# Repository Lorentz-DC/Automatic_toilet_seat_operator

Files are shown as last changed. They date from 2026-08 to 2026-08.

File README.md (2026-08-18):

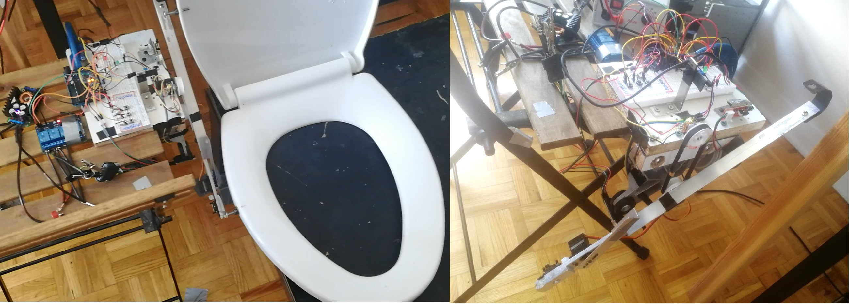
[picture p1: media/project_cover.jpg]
project cover:

# Automatic_toilet_seat_operator
A toggle-activated rotating armature system to raise up and close either the top or both toilet seats. The armature is driven by a car wiper motor and a servo, while the system runs on Arduino code with IR sensors to limit its positions during rotation. 

Load test demostration:

load_test

load testing video with explaination on youtube: https://youtu.be/TG4GU5XdJvA?si=c8EunXvwlVA2-hOE

**Introduction:**

As a guy living with my girlfriend and our cat, I really don't like touching the toilet lids every time I am asked to put the seats down. So I built a automatic toilet seat operator, featuring a set of rotating aluminum armature with a car wiper motor driving the main arm, and a servo motor bolted to the end of the main arm driving a smaller arm. 

The main idea of the design is that when activated, the armature will catch the bolts attached to the toilet lids, and lift up either the top lid or both of the lids, and then push the lids back down. When the main arm alone rotates in clockwise direction, it will only catch the bolt on the upper lid and lift it up; When the servo motor spins down the smaller arm, the main armature will be extended to reach and catch the front bolt of the bottom lid; Therefore, when the arm lifts, both of the lids will be lifted. To lower the seats, the armature simply rotates in reverse to push the lids over, after which they will fall back down themselves. 

With this said, the current version of the code logic works best on a slow closing toilet seat, since otherwise for a set of free closing toilet seat, the lids will slam loudly every time they are pushed back down. 

Hardware View:
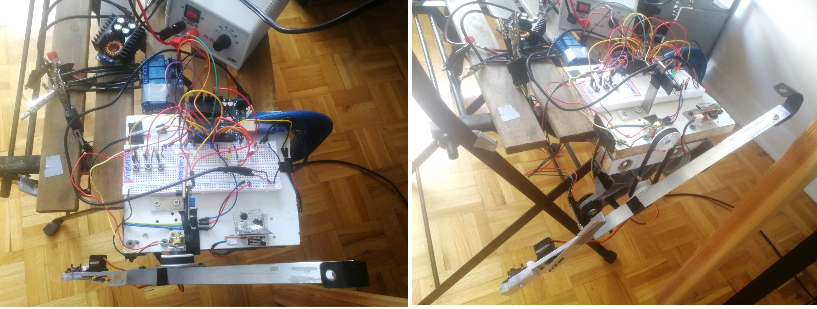
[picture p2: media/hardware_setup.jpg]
Hardware View:

 
**Main Components:**

The main wiper motor is activated by a 2-relay system powered by a 12V 2A DC source with an optional step-down buck converter to regulate speed and torque,  while the Arduino and servo motor can be powered by a standard 5v phone charger. Preferably, the servo motor should have its own power supply so that it does not sag the current on the arduino. 

The mechanism is controlled by 3 toggle buttons: Button 1 raise the top lid. Button 2 latches the small arm down with the servo, extending the main arm, and then the main arm lifts up both lids. Button 3: reverses the main arm to push the lids back down. 

The rotating arm tells its position by two IR sensors: bottom IR sensor for homing position, and a top IR sensor for when the arm reaches to about 90 degree zenith of rotation. On initial start up, the system will detect if the arm is resting at home position to allow inputs, if not, the system will enter a float warming state and a manual reset is required to bring the armature back to homing position. 
There is also a rotation tracking system featuring a set gears with a timing belt coupled to the motor shaft and to a potentiometer, however, this is an optional redundancy system added for extra safety. 

Due to the design, the servo motor casing cannot allow the armature to rotate freely the full 360 degree. For safety, a limit switch is placed in the path of the servo casing, and will stop all system movements if activated. In this case, a float state warning will also activate demanding manual reset. I've had an unfortunate test incident where my faulty code failed to activate the limit switch and the servo casing hit the wood block, as it was at the time running on a 12V 15A DC source, there was so much torque that the plastic servo casing got ripped right off the aluminum arm. 

Wiring Diagram:
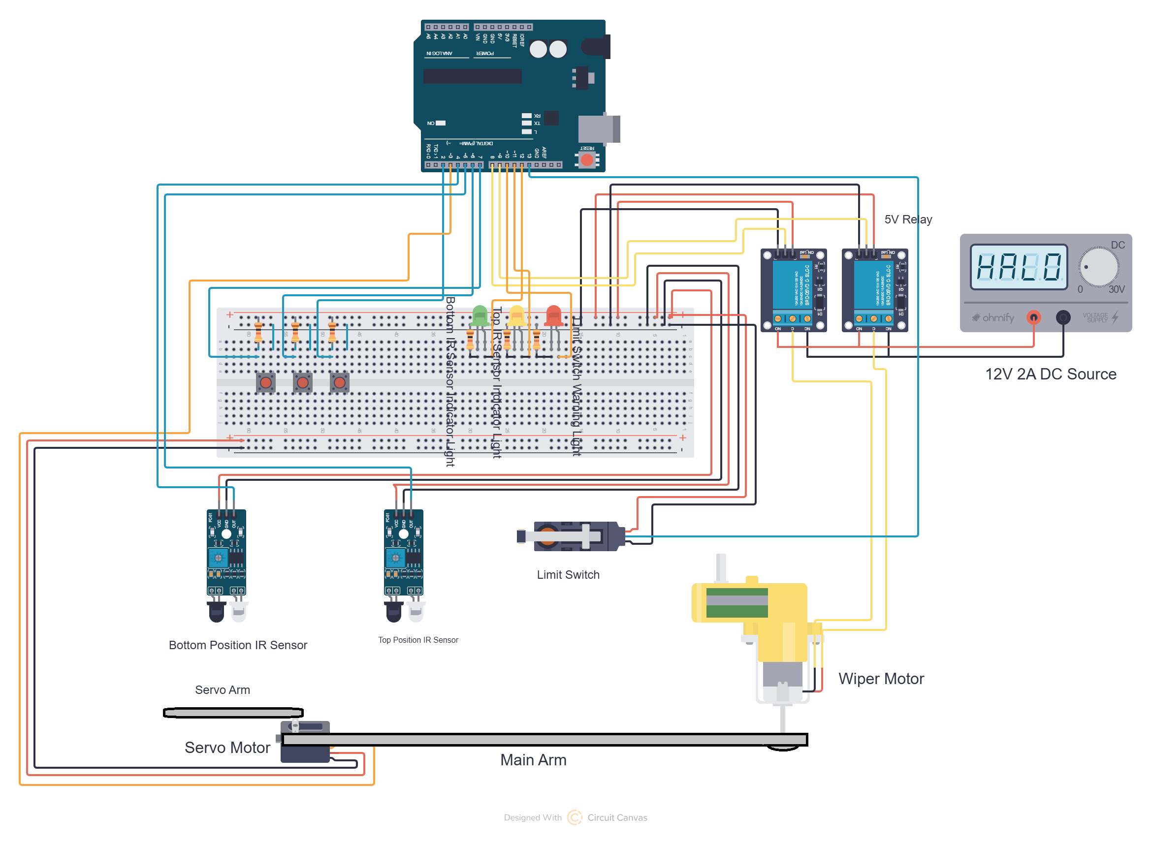
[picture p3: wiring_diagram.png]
Wiring Diagram:


**Relay and Motor Wiring:**

2-relay H-Bridge: I used a 2-relay configuration from a 4-channel module, wiring the motor leads directly to the Common (COM) terminals. This design Electrical Interlock: Normally Closed (NC) pins connect to system Ground, and Normally Open (NO) pins tie to the positive DC motor supply line. This physical wiring layout makes it structurally impossible to create a direct short-circuit across the DC power supply, regardless of code errors. 

Relay wiring diagram:

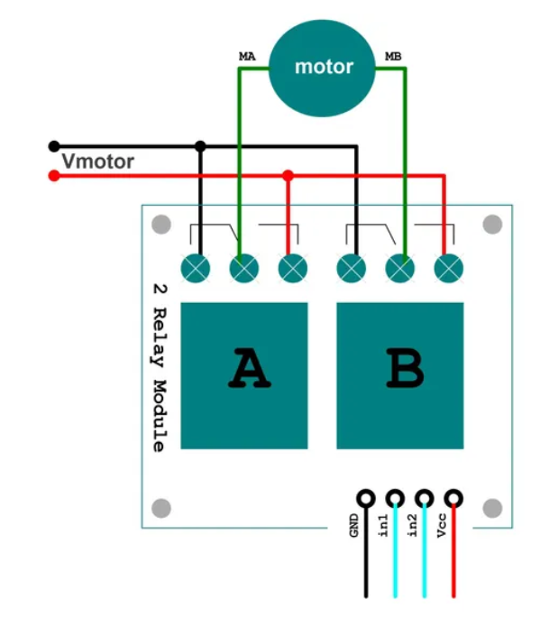
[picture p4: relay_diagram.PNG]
Relay wiring diagram:


**Armature Movement:**

Sequence of movement:
1. lifting up only the top lid;
2. Reverse to push lid down;
3. lifting up both lids by activating the servo and extending the arm;
4. Reverse to push both lids down.

Demonstration of movement logic of the armature:

armature demo

YouTube video link: https://youtu.be/BwDyFDnwye8?si=BkIoQYhQGPaKe0z8

**Arduino Code Structure:**

Arduino code file:
Arduino code file:

The software is organized into three clean layers that split reading sensors, deciding what to do, and moving the motor. This prevents glitches and keeps the hardware safe. 

1. Sensor & Button Inputs (Modular Functions): Functions like IR_Sensors(), Limit_Switch(), and the button controllers run continuously on every loop cycle. They read input data, and translate button presses into simple internal request flags. 

2. Brain & Decision Engine (Switch-Case Structure):The core logic uses a clean switch-case state machine. It handles one step at a time (like HOME, LATCHING, or LIFTING) and  blocks out the other states. Instead of turning on pins directly, this section only updates internal state-flag variables to map out the desired direction. 

3. Motor Driver (Main Loop Activation):Physical relay pins are only permitted to switch at the very end of the main loop(). This dedicated output block acts as a gatekeeper: it checks key state-flag motion variables (e.g: clockwise_direction_state, motion_activate, and servo_liftdown) and executes the final movement on the armature.

Code logic flowchart
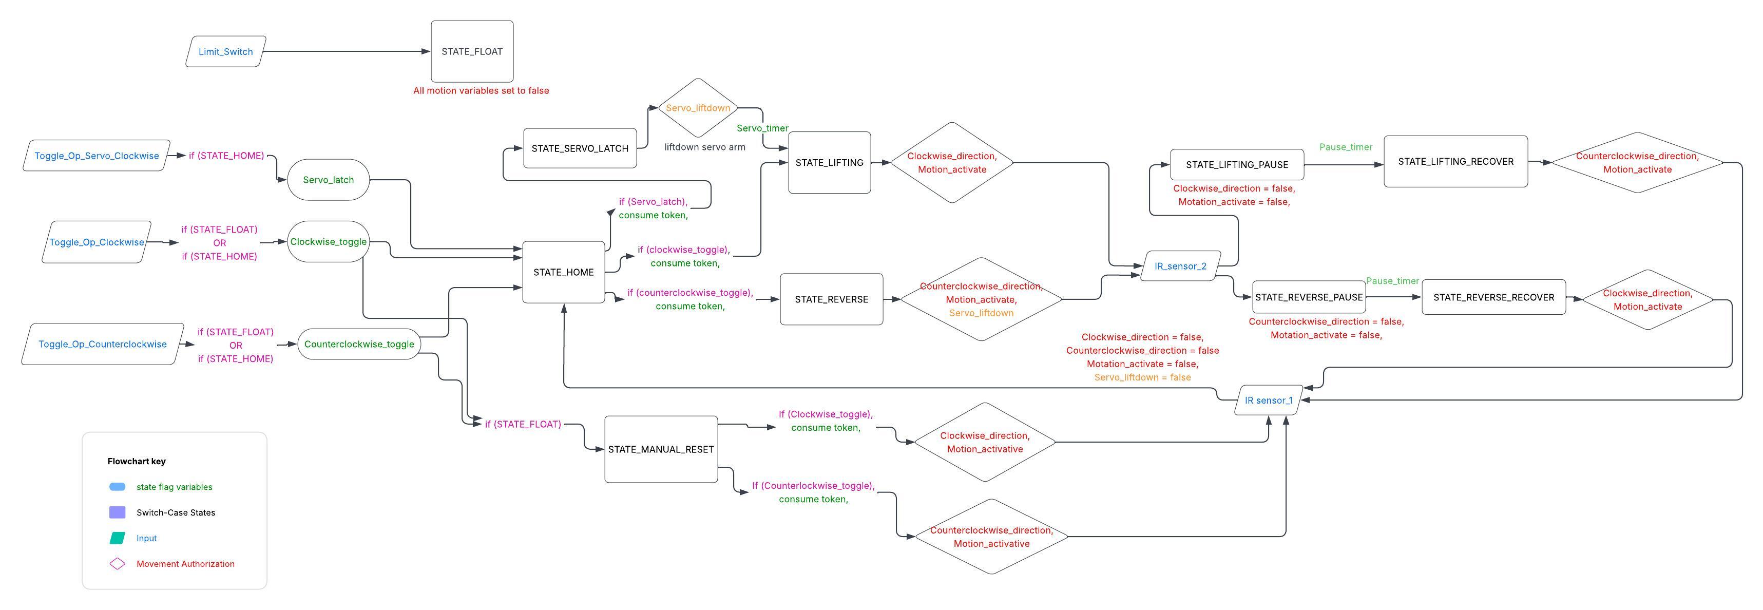
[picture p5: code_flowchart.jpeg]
Code logic flowchart:


**Additional Features:**

**Rotation tracking with potentiometer and 3D-printed GT2 sear set**

While the IR sensors are sufficient to limit arm rotation, I added a redundancy rotation tracking system with a potentiometer and GT2 gear-belt set, where the main arm gear is coupled around the motor shaft, and the potentiometer gear sits on the potentiometer above. When the main arm rotates, the potentiometer will have a 1-1 ratio rotation, and the Arduino will pick up its analog reading (0-1023) and map on to the rotation angle. However this system is not very accurate and prone to gradual slippage, so I've not incorporated it into the main program. Nevertheless, in the arduino code, the tracking function is there, and will print out the real-time rotation data of the potentiometer on the monitor. 

the main reference for my Fusion design is as follows: 
https://youtu.be/PDNIiLSTzG4?si=cXLuie5WhYatIrrd  

3D printed potentiometer GT2 gear set:
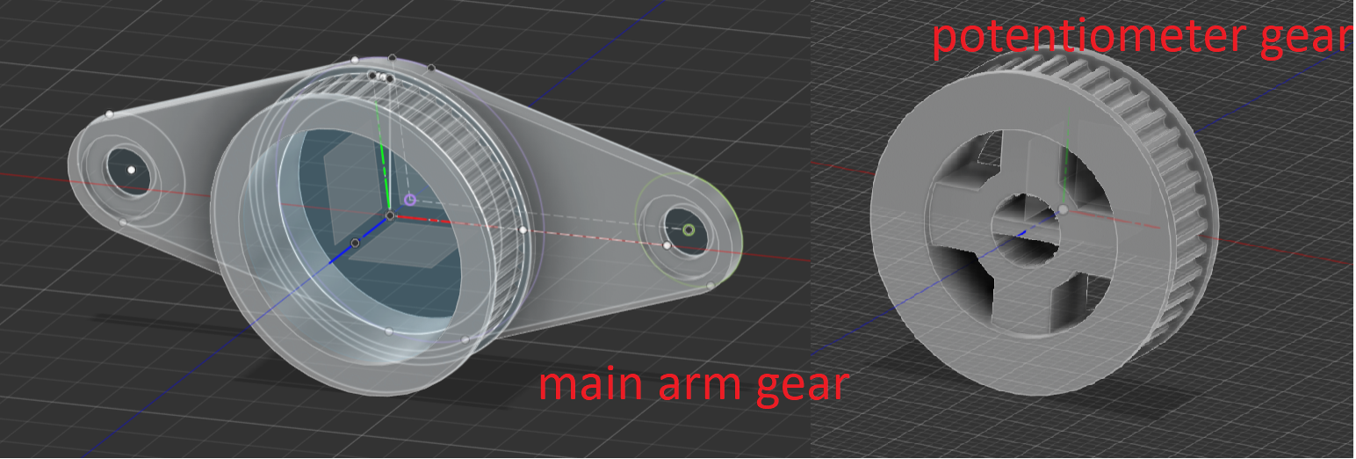
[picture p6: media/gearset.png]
3D printed potentiometer GT2 gear set

the Autodesk Fusion files can be found in the main repository: 

potentiometer gear  
main gear

**Voltage Control and Current Protection:**

Step-down buck converter with CV and CC control (optional): controls main arm movement speed by adjusting step-down voltage; Controls torque by adjusting current ceiling. 

TVS diodes: soldered Transient Voltage suppression diodes across relay terminals for voltage spike protection on the motor side.

Relay protection:
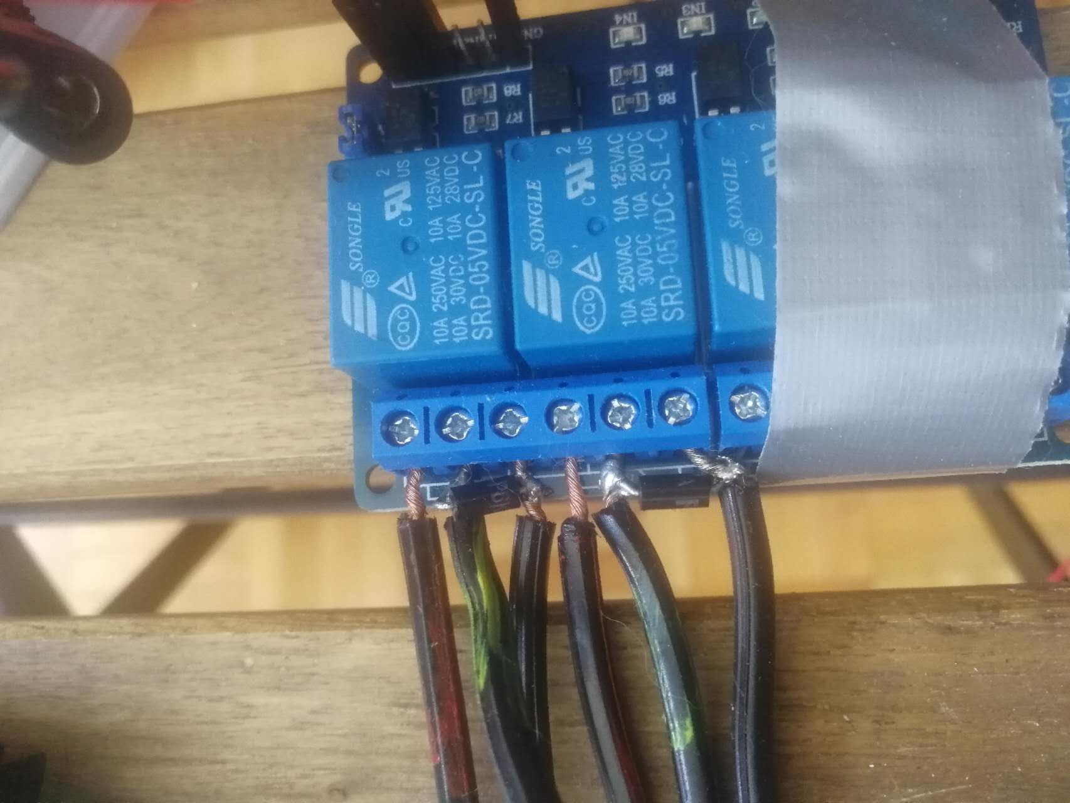
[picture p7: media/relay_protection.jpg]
Relay protection


**Upcoming bathroom Installation:**

As this project has been successfully tested, the next step will be actual installation in the bathroom so that the system will be fully functional. Which will involve many more upcoming works: 

Upgrading push buttons; 

Adding a touchless motion sensor relay switch to power on and off the system upon entering and exiting the bathroom; 

Environment-proofing, wiring and electrical safety; 

Slotted L brackets for position calibration (front-back, up-down, left-right); 

Convincing my gf to actually put it next to the toilet, which would perhaps, be the ultimate challenge.

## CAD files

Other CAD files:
Main_Gear_update_Jul08.f3d
Potentiometer_Gear_Update_Jul08.f3d

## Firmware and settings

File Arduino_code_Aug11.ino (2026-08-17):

#include <Servo.h>
Servo myServo;  // Create a servo object

// Pin Configuration
const int Servo_output_pin = 3;
const int IR_sensor1_pin = 4;  // Reset position (Lid down / Home)
const int IR_sensor2_pin = 5;  // Stop position (Lid fully up / Zenith)
const int Pot_pin = A0; // Potentiometer input
const int limit_switch_pin = 13; // Critical material fail-safe
const int clockwise_output_pin = 8;    // ACTIVE LOW (CW Lift Relay)
const int counterclock_output_pin = 9;  // ACTIVE LOW (CCW Lower Relay)
const int clockwise_servo_toggle_pin = 2;
const int clockwise_toggle_pin = 6;
const int counterclock_toggle_pin = 7;
const int LED1_pin = 12;  // sensor1 green light 
const int LED2_pin = 11;  // sensor2 yellow light
const int LED3_pin = 10;  // Limit Switch warning red light


// Potentiometer range:
/* Analog values range from 0 to 1023: starting point (lowest): 1023; Max rotation (highest): 0; UPLIFT ROTATING: CLOCKWISE
resting lowest: 970; home range: 750-850; zenith range: 400-350

const int POT_REVERSE_ZENITH_TARGET = 930; //arm at zenith pushing lid down
const int POT_HOME_TARGET = 655;    // resting position
const int POT_ZENITH_TARGET = 225;  // fully lift up 
const int POT_BALLPARK_TOLERANCE = 40; // 40-digit deadband tolerance for belt slop
*/

// // --- State management ---
enum SystemState { 
STATE_FLOAT, 
STATE_HOME, 
STATE_Servo_latch,
STATE_LIFTING, 
STATE_PAUSED, 
STATE_LIFTING_RECOVER, 
STATE_REVERSE, 
STATE_REVERSE_PAUSED, 
STATE_REVERSE_RECOVER,
STATE_MANUAL_RESET
};
// NEW: System boots into FLOAT state to handle initial position confirmation safely
SystemState current_state = STATE_FLOAT;  

// NEW: Ballpark tracking condition outputs
/*
boolean pot_at_home = false;
boolean pot_at_zenith = false;
boolean pot_at_reverse_zenith = false;
*/

boolean sensor1_activate = false;
boolean sensor2_activate = false;

boolean Clockwise_direction = false;
boolean Counterclock_direction = false;
boolean Motion_activate = false;

boolean Clockwise_toggle = false;
boolean Counterclock_toggle = false;

//clockwise toggle
boolean old_input_state_clockwise = HIGH;
bool current_button_state_clockwise= HIGH;  

boolean old_input_state_servo = HIGH;
boolean current_input_state_servo = HIGH;

unsigned long servo_start_time = 0;
bool servo_timer_state = false;


//counterclock toggle 
boolean old_input_state_counterclock = HIGH;

boolean Servo_latch = false;
boolean Servo_liftdown = false;
boolean blink_sequence = false;
boolean LED_blink_state = LOW; 

// --- Non-blocking timers --- 
unsigned long previousMillis = 0;
const long blink_interval = 500; // Frequency of Serial updates and reading (250ms)
const long print_interval = 50;
// Non-blocking pause tracking variables
unsigned long pause_start_time = 0;
const unsigned long pause_duration = 3000; // Safe 0.5-second electrical discharge window
// NEW: Boot/Homing timeout guard variable
const unsigned long servo_interval = 500;


bool IR_Sensors() {
  // Read raw inputs as fast as hardware allows
  bool sensor_reading_1 = digitalRead(IR_sensor1_pin);
  bool sensor_reading_2 = digitalRead(IR_sensor2_pin);
  // Evaluate Sensor 1 (Instantaneous response)
  digitalWrite(LED1_pin, !sensor_reading_1);
  sensor1_activate = !sensor_reading_1;
  // Evaluate Sensor 2 (Instantaneous response)
  digitalWrite(LED2_pin, !sensor_reading_2);
  sensor2_activate = !sensor_reading_2;
}

bool Limit_Switch() {
  // Hard Failure Limit Switch Guard
  if (digitalRead(limit_switch_pin) == LOW) {
    digitalWrite(LED3_pin, HIGH);
    Clockwise_direction = false;
    Counterclock_direction = false; //stop all movements
    Motion_activate = false;
    current_state = STATE_FLOAT; //declare warning state
  }
  if (digitalRead(limit_switch_pin) == HIGH && current_state != STATE_FLOAT) {
    digitalWrite(LED3_pin, LOW);
  }
}


bool Toggle_Op_Clockwise_main() {
  // Global/Static memory states that survive frame cycles

  // Read and debounce input pin
  bool new_input_state_clockwise1 = digitalRead(clockwise_toggle_pin); 
  delay(2);
  bool new_input_state_clockwise2 = digitalRead(clockwise_toggle_pin); 
  delay(2);
  bool new_input_state_clockwise3 = digitalRead(clockwise_toggle_pin);

  if ((new_input_state_clockwise1 == new_input_state_clockwise2) && (new_input_state_clockwise1 == new_input_state_clockwise3)) {
    current_button_state_clockwise = new_input_state_clockwise3;
  }

  // --- Step 1: Detect Falling Edge (New Button Press) ---
  if (current_button_state_clockwise!= old_input_state_clockwise){

      if (current_button_state_clockwise == LOW){
        if (current_state == STATE_FLOAT){
        Clockwise_toggle = true;
        }

        else if(current_state == STATE_HOME) {
         Clockwise_toggle = true;//consume in state_ops

            }//current_button_state_clockwise== LOW
      }//current_button_state_clockwise == LOW

   old_input_state_clockwise = current_button_state_clockwise; // Save edge state
  }//(current_button_state_clockwise!= old_input_state_clockwise)

      // Arm movement handles staging in the State_Operations pipeline next!
}//function bracket

bool Toggle_Op_Clockwise_Servo(){

bool new_input_state_servo1 = digitalRead(clockwise_servo_toggle_pin); 
  delay(2);
  bool new_input_state_servo2 = digitalRead(clockwise_servo_toggle_pin); 
  delay(2);
  bool new_input_state_servo3 = digitalRead(clockwise_servo_toggle_pin);

  if ((new_input_state_servo1 == new_input_state_servo2) && (new_input_state_servo1 == new_input_state_servo3)) {
    current_input_state_servo = new_input_state_servo3;
  }

  // --- Step 1: Detect Falling Edge (New Button Press) ---
  if (current_input_state_servo!= old_input_state_servo){

      if (current_input_state_servo == LOW){

        if(current_state == STATE_HOME) {
         Servo_latch = true;//consume in state_ops

            }//current_button_state_clockwise== LOW
      }//current_button_state_clockwise == LOW

   old_input_state_servo = current_input_state_servo; // Save edge state
  }//(current_button_state_clockwise!= old_input_state_clockwise)


}

bool Toggle_Op_Counterclock() {
  bool new_input_state_counterclock1 = digitalRead(counterclock_toggle_pin);
  delay(2);
  bool new_input_state_counterclock2 = digitalRead(counterclock_toggle_pin);
  delay(2);
  bool new_input_state_counterclock3 = digitalRead(counterclock_toggle_pin);
 
  // if all 3 values are the same we can continue
  if ((new_input_state_counterclock1 == new_input_state_counterclock2) && (new_input_state_counterclock1 == new_input_state_counterclock3)) {
    if (new_input_state_counterclock3 != old_input_state_counterclock){
       old_input_state_counterclock = new_input_state_counterclock3;

       if ((new_input_state_counterclock3 == LOW && current_state == STATE_HOME)||(new_input_state_counterclock3 == LOW && current_state == STATE_FLOAT)){
          Counterclock_toggle = true;//consume in state_ops
       }
       
       else if (new_input_state_counterclock3 == HIGH){
        Counterclock_toggle = false;
      }  
  }
}
}//FUNCTION
// NEW: Dual-redundancy analog window tracker
/* void Rotation_Tracking() {
  int Pot_reading = analogRead(Pot_pin);
  
  // Evaluate ballpark position windows using deadband tolerances
  pot_at_home = (abs(Pot_reading - POT_HOME_TARGET) <= POT_BALLPARK_TOLERANCE);
  pot_at_zenith = (abs(Pot_reading - POT_ZENITH_TARGET) <= POT_BALLPARK_TOLERANCE);
  pot_at_reverse_zenith = (abs(Pot_reading - POT_REVERSE_ZENITH_TARGET) <= POT_BALLPARK_TOLERANCE);
}
*/
bool Manual_Reset(){
  if (current_state == STATE_FLOAT){
    if(Clockwise_toggle == true||Counterclock_toggle == true){
      current_state = STATE_MANUAL_RESET;
  } //clockwise reset
  }
}//function bracket

void State_Operations() {
  // NEW Phase 0: Safe On-Boot Floating State Homing Routine
 
    /* POT_REVERSE_ZENITH_TARGET = 930; POT_HOME_TARGET = 655;  POT_ZENITH_TARGET = 225; POT_BALLPARK_TOLERANCE = 40; 
    SystemStates: STATE_FLOAT, STATE_HOME, STATE_LIFTING, STATE_PAUSED, STATE_LIFTING_RECOVER, STATE_WARNING 

    if reverse range, clockwise until home sensor on; 
    if home range: (uncertain states where home sensor is not on) if the initial position is under the home sensor, rotate clockwise until home sensor is on;
    if the initial position is above the homesensor, turn clockwise and no sensor turns on and/or zenith sensor turns on or rotation is already in life/reverse range, go back counterclockwise until home sensor is on;
    if in lift range or danger zone, turn counterclockwise until home sensor is on. 
    */
    // If the arm is already happily at home on startup, exit float mode instantly
  if (sensor1_activate == true && 
      current_state != STATE_LIFTING && 
      current_state != STATE_REVERSE &&
      current_state != STATE_Servo_latch){

      current_state = STATE_HOME;
       // Only accept user inputs if the initialization float/homing phase is done!
  }

  if (current_state == STATE_FLOAT){ //declare warning state)
    Motion_activate = false;
    Clockwise_direction = false;
    Counterclock_direction = false;
  }

  switch (current_state) {
    case STATE_MANUAL_RESET: 
        if (Clockwise_toggle == true){
        Clockwise_toggle = false; //consume token
        Clockwise_direction = true;//authorize direction;
        Motion_activate = true;
        }
        else if(Counterclock_toggle == true){
        Counterclock_toggle = false;//consume token
        Counterclock_direction = true;
        Motion_activate = true;
        }

      if(sensor1_activate == true){
      Clockwise_direction = false;
      Counterclock_direction = false;
      Motion_activate = false;
      current_state = STATE_HOME;
      }
    break;

    case STATE_HOME:                            //
      Motion_activate = false;                  // Enforce absolute idle silence
      Clockwise_direction = false;       //
      Counterclock_direction = false;     //
      Servo_liftdown = false;
        if (Servo_latch == true){
          current_state = STATE_Servo_latch;
          Servo_latch = false; //consume token
        }
        else if (Clockwise_toggle == true) {           //
        Clockwise_toggle = false;               // Consume token safely
        current_state = STATE_LIFTING;          //
        } 
        else if (Counterclock_toggle == true) {   //
        Counterclock_toggle = false;            // Consume token
        current_state = STATE_REVERSE;          //
        }
    break;

    case STATE_LIFTING:
      Clockwise_direction = true;
      Motion_activate = true;

        if (sensor2_activate == true) {
          Clockwise_direction = false;
          Counterclock_direction = false;
          Motion_activate = false;
          pause_start_time = millis(); 
          current_state = STATE_PAUSED; 
    }
    break;

    case STATE_PAUSED:
     if (millis() - pause_start_time >= pause_duration) {
      current_state = STATE_LIFTING_RECOVER;
    }
    break;

    case STATE_LIFTING_RECOVER:
     Clockwise_direction = false;
    Counterclock_direction = true;
    Motion_activate = true;

     if (sensor1_activate == true) {
      Clockwise_direction = false;
      Counterclock_direction = false;
      Motion_activate = false;
      current_state = STATE_HOME;
     }
    break;

  case STATE_REVERSE:                       //
      Clockwise_direction = false;       //
      Counterclock_direction = true;     // Force motor downwards
      Motion_activate = true;   
      Servo_liftdown = true;              //

      if (sensor2_activate == true) { //
        Motion_activate = false; //
        Counterclock_direction = false; //
        pause_start_time = millis(); //
        current_state = STATE_REVERSE_PAUSED; //
          }
    break;

    case STATE_REVERSE_PAUSED: //
        if (millis() - pause_start_time >= pause_duration) { //
            current_state = STATE_REVERSE_RECOVER; //
            }
      break;

    case STATE_REVERSE_RECOVER: //
          Clockwise_direction = true; // Pull back home
          Counterclock_direction = false; //
          Motion_activate = true; //

            if (sensor1_activate == true) { //
            Motion_activate = false; //
              Clockwise_direction = false; //
              current_state = STATE_HOME; //
              }
          break;
  

  case STATE_Servo_latch:
   Servo_liftdown = true;//consume in state_ops
   if (servo_timer_state == false){
      servo_start_time = millis(); // Benchmark time for the motor delay window
      servo_timer_state = true;}

    if(servo_timer_state == true && millis()-servo_start_time >= servo_interval){
    servo_timer_state = false;
    servo_start_time = 0;
    current_state = STATE_LIFTING; //consume in state_ops
  }
  break;

/*

  /*else if {
      // Timeout supervisor: if the motor drives backward for 5 seconds and finds nothing, shut it down
      if (millis() - float_start_time > FLOAT_TIMEOUT_MAX) {
        digitalWrite(clockwise_output_pin, HIGH);
        digitalWrite(counterclock_output_pin, HIGH);
        Serial.println("CRITICAL ERROR: Homing Timeout! Check sensors or physical arm jams.");
        while(1); // Permanent safe microcontroller loop lock
      }
    }*/
    

  }//switch bracket
}//function bracket

bool Initialization(){ //runs once on start-up

    Clockwise_direction = false;
    Counterclock_direction = false;
    Motion_activate = false;
    Servo_liftdown = false;

    if (sensor1_activate == true) {
      current_state = STATE_HOME;
      Serial.println("Initial System State AT HOME, System good to go");
      Serial.println("Pot: "); Serial.println(analogRead(Pot_pin));
      Serial.print("   State: "); Serial.println(current_state);
    }
    else{
      current_state = STATE_FLOAT;
      Serial.println("Initial System State FLOATING, MANUAL RESET REQUIRED");
      Serial.println("Pot: "); Serial.println(analogRead(Pot_pin));
      Serial.print("   State: "); Serial.println(current_state);
    }
}

bool Blinking_Sequence(){
if (current_state == STATE_FLOAT){
    blink_sequence = true;
     unsigned long currentMillis = millis();
    if (currentMillis - previousMillis > blink_interval) {
      previousMillis = currentMillis; 
      if (LED_blink_state == LOW){
        LED_blink_state = HIGH;}
      else {
        LED_blink_state = LOW;
      }
    digitalWrite(LED3_pin, LED_blink_state);
    }
}
else{
  blink_sequence = false;
}
}

void setup() {
  Serial.begin(115200); 

  myServo.attach(Servo_output_pin);  // Attaches the servo on pin 3

  // Pull-up protections on inputs to kill motor EM field brush disruptions
  pinMode(IR_sensor1_pin, INPUT);
  pinMode(IR_sensor2_pin, INPUT);
  pinMode(Pot_pin, INPUT);
  pinMode(limit_switch_pin, INPUT_PULLUP);
  pinMode(clockwise_toggle_pin, INPUT_PULLUP);
  pinMode(counterclock_toggle_pin, INPUT_PULLUP);

  pinMode(clockwise_output_pin, OUTPUT);
  pinMode(counterclock_output_pin, OUTPUT);
  pinMode(LED1_pin, OUTPUT);
  pinMode(LED2_pin, OUTPUT);
  pinMode(LED3_pin, OUTPUT);

  // Active-Low Ground state: Lock them off immediately on boot
  digitalWrite(clockwise_output_pin, HIGH); 
  digitalWrite(counterclock_output_pin, HIGH); 
  Counterclock_direction = false;
  Clockwise_direction = false;
  Motion_activate = false;
  digitalWrite(LED1_pin, LOW);
  digitalWrite(LED2_pin, LOW);
  digitalWrite(LED3_pin, LOW);

  //initialization 
  IR_Sensors();
  //Rotation_Tracking();
  Initialization();
  myServo.write(5);

  delay(100); // Give the 5V power rail 50ms to fully stabilize
  old_input_state_clockwise = digitalRead(clockwise_toggle_pin); 
  
}



void loop() {
  IR_Sensors();
  //Rotation_Tracking(); // NEW: Track the analog potentiometer position concurrently
  Limit_Switch();
  Toggle_Op_Clockwise_main();
  Toggle_Op_Clockwise_Servo();
  Toggle_Op_Counterclock();
  //STATE_DETECTION();
  Blinking_Sequence();
  Manual_Reset();
  State_Operations();

 //-------------------------------------------------------
 //SystemStates: [STATE_FLOAT, STATE_HOME, STATE_LIFTING, STATE_PAUSED, STATE_LIFTING_RECOVER, STATE_REVERSE, STATE_REVERSE_PAUSED, STATE_REVERSE_RECOVER, STATE_WARNING]
    if(Servo_liftdown == true){
      myServo.write(159);
    }
    else if(Servo_liftdown == false){
      myServo.write(5);
    }


  if (Clockwise_direction == true && Counterclock_direction == false && Motion_activate == true) { 
    digitalWrite(clockwise_output_pin, LOW);     // CW Relay ON (Drive Up)
    digitalWrite(counterclock_output_pin, HIGH);    // CCW Relay OFF
  }
 else if (Clockwise_direction == false && Counterclock_direction == true && Motion_activate == true) { 
    digitalWrite(clockwise_output_pin, HIGH);     // CW Relay ON (Drive Up)
    digitalWrite(counterclock_output_pin, LOW);    // CCW Relay OFF
  }
  else {
     digitalWrite(clockwise_output_pin, HIGH);     // CW Relay ON (Drive Up)
    digitalWrite(counterclock_output_pin, HIGH);    // CCW Relay OFF
  }

 //--------------------------------------------------------

  // Live serial telemetry outputs
  if ((Clockwise_direction == true && Counterclock_direction == false && Motion_activate == true) ||(Clockwise_direction == false && Counterclock_direction == true && Motion_activate == true)){
  Serial.println("Pot: "); Serial.println(analogRead(Pot_pin));
  unsigned long currentMillis = millis();
  if (currentMillis - previousMillis >= print_interval) {
    previousMillis = currentMillis;
    Serial.print("   State: "); Serial.println(current_state);
    }

  }
}

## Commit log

2026-08-17 Update README with detailed project information
    Expanded project description, components, wiring, code structure, additional features, voltage control, and upcoming installation plans.
2026-08-17 Enhance README with detailed project information
    Added images, videos, and detailed explanations of the automatic toilet seat operator's components, wiring, and code structure. Included additional features and upcoming installation plans.
2026-08-17 Enhance README with project details and future plans
    Updated the README to include detailed project description, components, wiring, code structure, additional features, voltage control, and upcoming installation plans.
2026-08-17 Enhance README with hardware and wiring details
    Added hardware views, wiring diagrams, and detailed explanations of the toilet seat operator's components and code structure to the README.
2026-08-17 Change Arduino code file name in README
    Updated Arduino code file reference in README.
2026-08-17 Clarify description of toilet seat operator system
    Updated project description to clarify the use of IR sensors.
2026-08-17 Enhance README with rotation tracking feature details
    Added details about rotation tracking with a potentiometer and 3D-printed GT2 gear set, including limitations and references to design files.
2026-08-17 Enhance README with rotation tracking and safety details
    Added details about the rotation tracking system and its limitations. Updated the warning about the servo motor casing incident.
2026-08-17 Change code logic flowchart image from PNG to JPEG
    Updated image format for the code logic flowchart in README.
